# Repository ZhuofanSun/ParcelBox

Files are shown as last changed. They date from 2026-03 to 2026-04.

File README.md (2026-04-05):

# ParcelBox

ParcelBox is a Raspberry Pi smart parcel box prototype. It combines RFID access control, locker door actuation, live camera streaming, face detection with pan-tilt tracking, ultrasonic occupancy sensing, local audio/visual alerts, SQLite persistence, and a browser-based operations console into one device-side system.

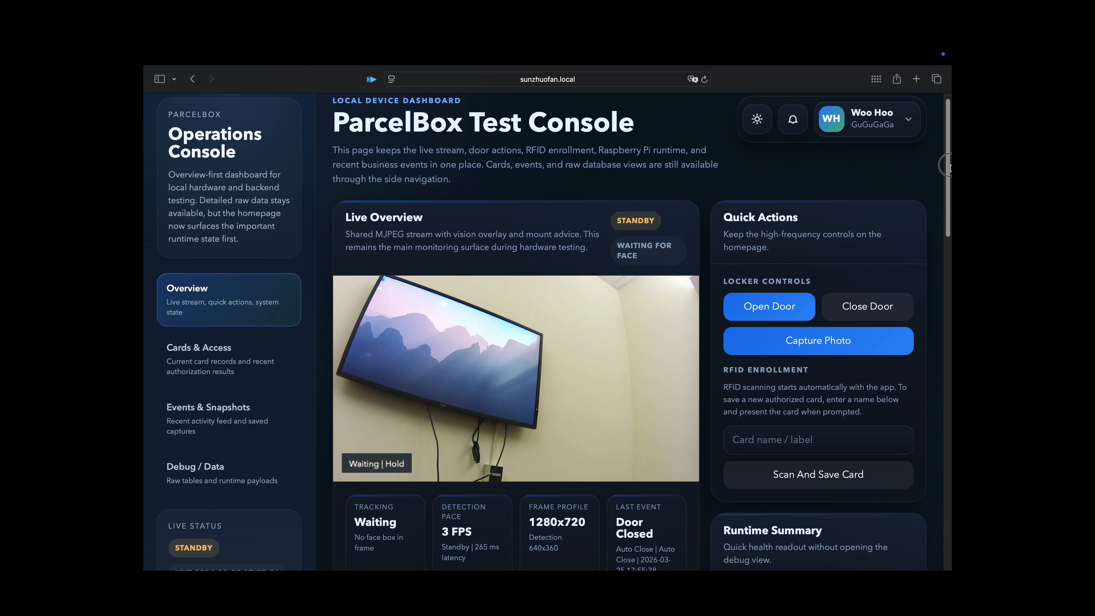
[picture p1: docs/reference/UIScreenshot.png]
ParcelBox dashboard


## Project Overview

The point of this project is not just to build a web page. It is to close the loop across a real hardware workflow:

- Read RFID cards and decide whether access should be granted
- Lock and unlock the compartment with a servo-driven door mechanism
- Provide live video, snapshots, and visual overlays from a CSI camera
- Detect faces, track them with a pan-tilt mount, recover from target loss, and drop into standby when idle
- Trigger door-open requests, email notifications, and local alarms from a physical button
- Persist cards, access attempts, door sessions, button requests, snapshots, and email schemes in local SQLite storage
- Expose the whole system through a browser console for monitoring, control, and debugging

This repository is scoped as a single-device prototype, not a cloud platform. The vision stack focuses on face detection and tracking rather than face recognition. Video delivery is handled with MJPEG plus WebSocket metadata instead of WebRTC.

## Team

- Zhuofan Sun - GitHub: [ZhuofanSun](https://github.com/ZhuofanSun)
- Jiayin Chen - GitHub: [Yinnc259](https://github.com/Yinnc259)
- Yangfei Wang - GitHub: [stayinnight1](https://github.com/stayinnight1)

## Showcase

### Events and Snapshots View

The homepage is meant for live status and quick control. The events and snapshots views are better for reviewing RFID activity, button requests, door sessions, and captured images.

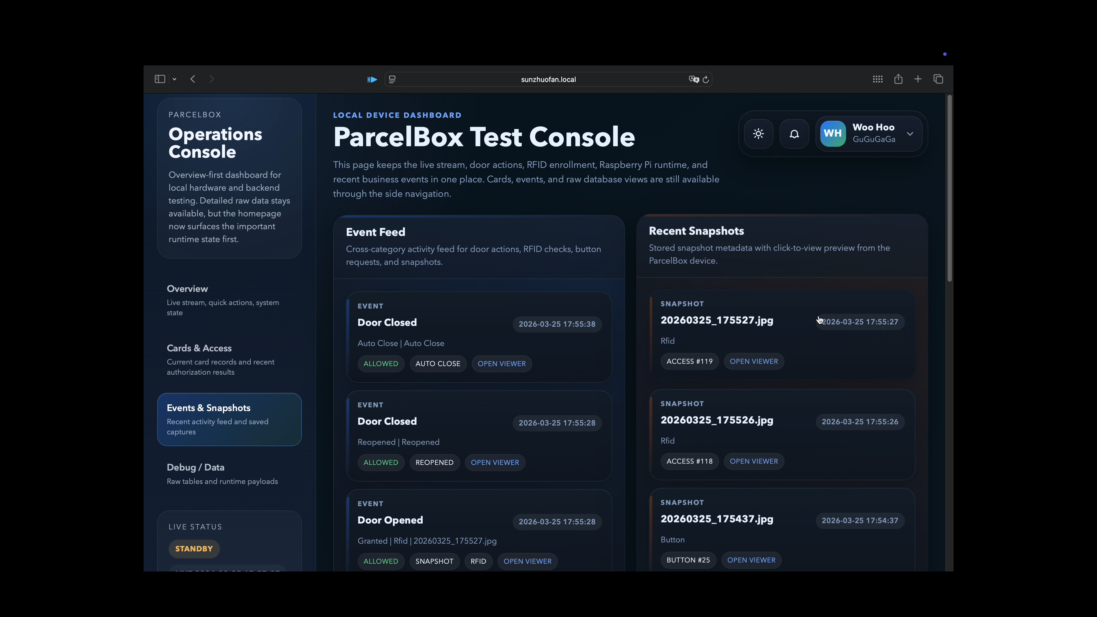
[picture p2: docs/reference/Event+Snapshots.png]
ParcelBox events and snapshots


### Hardware Wiring

The locker control hardware, camera mount, RFID reader, button, RGB LED, buzzer, and ultrasonic sensor are all wired around the Raspberry Pi. The following image is the most practical overall wiring reference for the prototype.

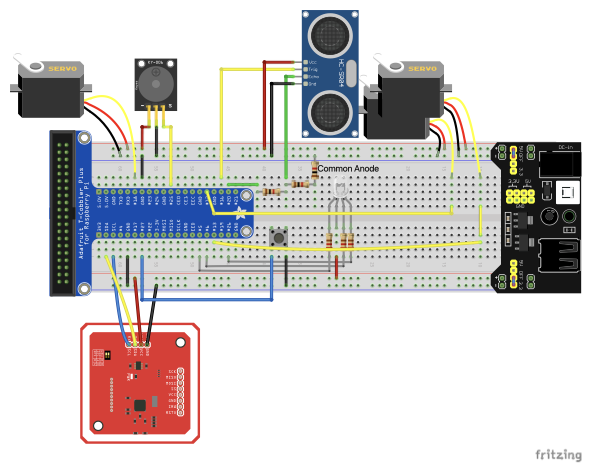
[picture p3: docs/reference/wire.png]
ParcelBox wiring diagram


If you want the schematic-style version, see [`docs/reference/wire_schem.png`](docs/reference/wire_schem.png).

## Core Capabilities

- Single-device integration: frontend, backend, drivers, and storage all run on the Raspberry Pi
- RFID access control: card enrollment, enable/disable state, and time-window authorization
- Locker workflow: open, close, auto-close, and post-close occupancy measurement
- Vision tracking: dual camera streams, low-resolution detection, high-resolution display, mount tracking, and standby mode
- Event capture: manual snapshots, RFID-triggered snapshots, button-triggered snapshots, and near-face snapshots
- Local alerts: unauthorized scans and repeated button presses can escalate to buzzer alarms and search behavior
- Browser operations console: live monitoring, event review, snapshot browsing, and device settings in one place

## Tech Stack

- Hardware: Raspberry Pi, PN532 RFID reader, CSI camera, 3 servo channels, ultrasonic sensor, button, RGB LED, buzzer
- Backend: FastAPI, Uvicorn, SQLite
- Vision: Picamera2, OpenCV, YuNet / Haar Cascade
- Frontend: plain HTML, CSS, and JavaScript
- Device control: `pigpio`, `RPi.GPIO`, Adafruit Blinka / PN532

## System Architecture

The repository is organized into five layers: browser console, web routes, core services, local data, and hardware drivers. `main.py` wires these services together at startup and exposes them through FastAPI.

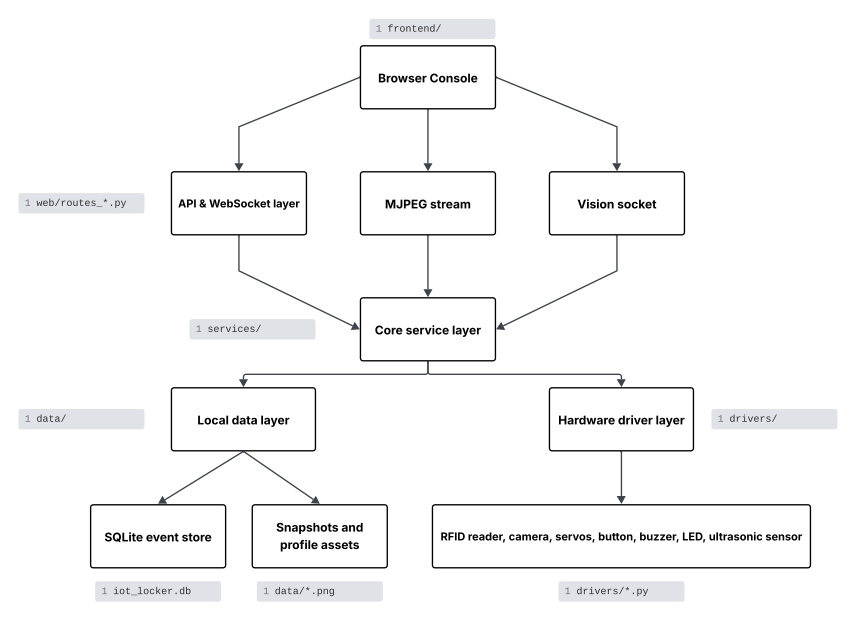
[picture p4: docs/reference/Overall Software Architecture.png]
Overall software architecture


The browser-to-device communication model is also intentionally simple:

- HTTP API for commands, settings writes, and polling-based status refresh
- MJPEG for the live video stream
- WebSocket for vision boxes, tracking state, button events, and other real-time overlay metadata

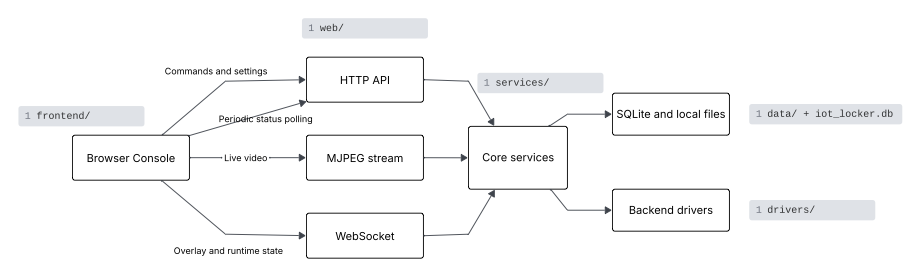
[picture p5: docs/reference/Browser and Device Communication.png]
Browser and device communication


## Main Workflows

### 1. RFID Unlock Flow

`LockerService` continuously polls `AccessService` in the background. When `AccessService` reads a UID from the PN532 reader, it normalizes the UID and evaluates whether the card exists, whether it is enabled, and whether the current time is inside the configured access window.

- If access is granted: record the result, capture a snapshot, drive the door servo open, and start the auto-close timer
- If access is denied: record the denied event, optionally attach a snapshot, and pass the event to `AlertService` for buzzer and escalation handling
- After the door closes: `OccupancyService` measures distance and classifies the locker as `occupied`, `empty`, or `door_not_closed`

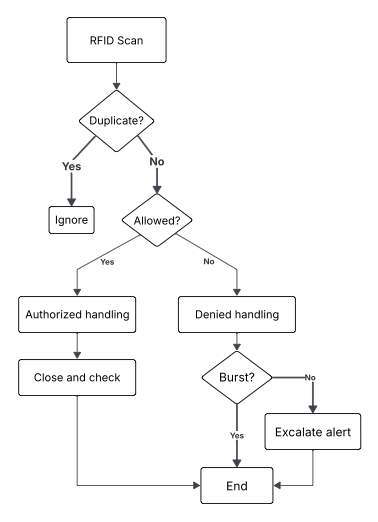
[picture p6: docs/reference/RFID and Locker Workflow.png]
RFID and locker workflow


### 2. Vision Detection and Pan-Tilt Tracking

`CameraService` maintains both the main stream and the lower-resolution detection stream. `VisionService` runs face detection on the detection stream, maps the boxes back to display resolution, and pushes the payload to the frontend over WebSocket. `CameraMountService` uses target offsets to drive the pan and tilt servos.

- Face detected: smooth the box, update the target center, and move the mount
- Face briefly lost: use short-term prediction to reduce visible jitter
- Face lost for longer: enter a recovery/search sweep, then return home if recovery fails
- No face for a while: drop to low-FPS standby mode to reduce idle load
- Face close enough to the camera: capture a one-time near-face snapshot

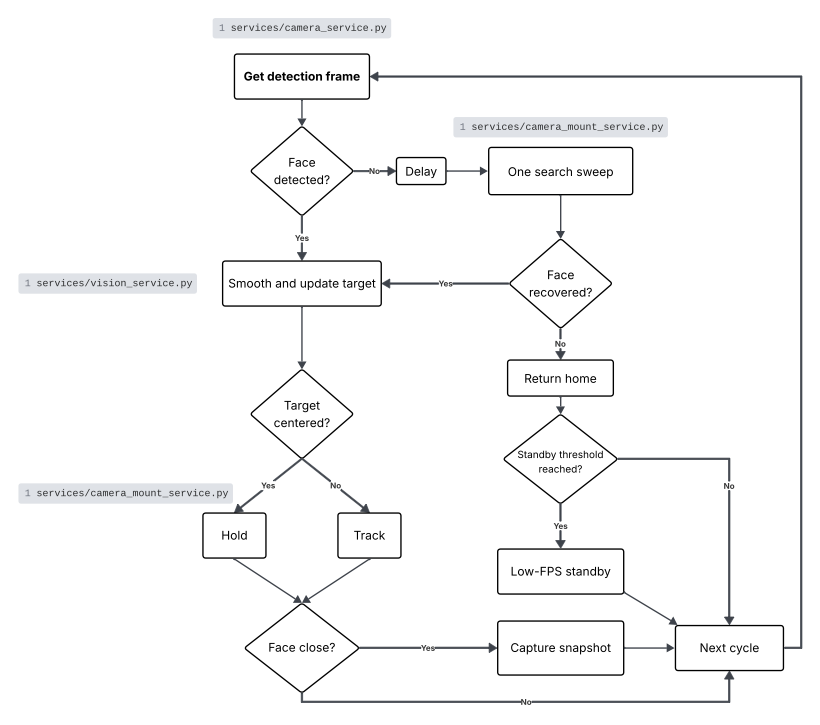
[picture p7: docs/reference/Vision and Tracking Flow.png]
Vision and tracking flow


### 3. Button, Notifications, and Event Flow

The system also maintains a separate hardware-button workflow:

- `ButtonService` listens to the GPIO button and can capture a snapshot and request an email notification
- `EmailNotificationService` sends a door-open request email using the currently enabled delivery scheme and applies duplicate suppression
- `AlertService` tracks burst conditions for rapid button presses and repeated unauthorized RFID scans
- `BuzzerService` and `LedService` provide local feedback
- `EventStore` consolidates button requests, snapshots, access attempts, and door sessions into SQLite for the frontend event and debug views

## Local Data Model

Runtime state is persisted in local SQLite storage. The main entities are:

- `rfid_card`: enrolled cards and their access rules
- `access_attempt`: the authorization result of each scan
- `door_session`: the full lifecycle of each open/close session
- `button_request`: button-triggered open requests and email delivery outcomes
- `snapshot`: captured images and their parent relationships
- `device_profile`: local console name, role, and avatar
- `email_subscription_scheme` / `email_subscription_recipient`: outbound email schemes and recipients

That means the card list, event feed, snapshot viewer, settings page, and debug tables in the browser are all reading from the same local source of truth.

## Project Structure

| Path | Role |
| --- | --- |
| `main.py` | Application entry point, service wiring, and FastAPI lifecycle setup |
| `config.py` | Central runtime configuration for GPIO, camera, mount, door, alerts, vision, web, and storage |
| `services/` | Business logic and background workers for RFID, locker control, vision, button handling, alerts, email, LEDs, and more |
| `web/` | FastAPI route layer for HTTP APIs, MJPEG streaming, and the vision WebSocket |
| `frontend/` | Static single-page console served directly by FastAPI, with no separate build step |
| `data/` | SQLite schema, `EventStore`, and snapshot path handling |
| `drivers/` | Low-level wrappers for the camera, PN532, servos, button, ultrasonic sensor, RGB LED, and buzzer |
| `scripts/` | Hardware smoke tests, Raspberry Pi sync scripts, runtime data pull scripts, and one-off migrations |
| `models/` | Vision model directory; the YuNet ONNX model is loaded from here by default |
| `docs/reference/` | UI screenshots, architecture diagrams, workflow diagrams, wiring references, and course materials |

If you want the fastest route through the codebase, this reading order works well:

1. `main.py`
2. `config.py`
3. `services/locker_service.py`
4. `services/access_service.py`
5. `services/camera_service.py`
6. `services/vision_service.py`
7. `services/camera_mount_service.py`
8. `data/event_store.py`
9. `web/routes_*.py`
10. `frontend/scripts/app.js`

## Key Modules

| Module | Responsibility |
| --- | --- |
| `AccessService` | RFID reads, card enrollment, and time-window authorization checks |
| `LockerService` | Scan processing, door state transitions, auto-close, and occupancy integration |
| `CameraService` | Camera initialization, shared stream frames, and snapshot capture |
| `VisionService` | Face detection, box smoothing, standby behavior, and near-face snapshot capture |
| `CameraMountService` | Home positioning, tracking, recovery, and search sweeps for the pan-tilt mount |
| `ButtonService` | Button listening, snapshot capture, and notification triggering |
| `AlertService` | Escalation logic for unauthorized scans and burst button activity |
| `EmailNotificationService` | Runtime email delivery for open requests and test emails |
| `EventStore` | SQLite persistence for cards, events, snapshots, settings, and email schemes |

## Runtime Boundaries

There are a few boundaries worth stating clearly:

- This is a single-device prototype, not a cloud multi-device platform
- Video uses MJPEG plus WebSocket because simplicity and stability matter more here than bandwidth efficiency
- Vision is limited to face detection and tracking, not identity recognition
- The frontend is plain static web content with no separate frontend build pipeline
- The best target environment is Raspberry Pi OS with working camera and GPIO access

## Before You Run It

Before starting the application, confirm the following:

- Raspberry Pi OS has camera and GPIO access enabled
- The hardware wiring matches the GPIO assignments in `config.py`
- `pigpiod` is available for stable servo control
- If you want YuNet, the model file exists at `models/face_detection_yunet_2023mar.onnx`
- If the YuNet model is missing, the OpenCV backend will fall back to Haar Cascade

## Installation and Startup

Install the Raspberry Pi system packages first:

```bash
sudo apt update
sudo apt install -y python3-picamera2 python3-opencv pigpio-tools python3-pigpio
```

Create a virtual environment and install the Python dependencies:

```bash
python3 -m venv .venv --system-site-packages
source .venv/bin/activate
pip install -r requirements.txt
```

`Picamera2` is installed as a system package, so the virtual environment keeps `--system-site-packages`.

Start `pigpiod`:

```bash
sudo systemctl enable --now pigpiod
```

If you want to run a quick hardware smoke test first:

```bash
./.venv/bin/python scripts/hardware_smoke_test.py all
```

Start the application:

```bash
./.venv/bin/python main.py
```

Then open the dashboard in a browser:

- `http://raspberrypi.local:8000`
- `http://<pi-lan-ip>:8000`

## Sync and Deploy to the Raspberry Pi

If you are developing on another machine and want to push the project to the Raspberry Pi, use the built-in sync script:

```bash
./scripts/sync_to_pi.sh
```

If you want to pull runtime data back from the Raspberry Pi, including the SQLite database and snapshots:

```bash
./scripts/pull_runtime_data_from_pi.sh
```

Both scripts support environment-variable overrides for the target host and path:

```bash
PI_HOST=<your-pi-host> PI_USER=<your-pi-user> PI_PORT=22 REMOTE_DIR=<remote-path> ./scripts/sync_to_pi.sh
```

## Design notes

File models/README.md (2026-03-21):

# Vision Models

The current Phase 2 baseline uses the `opencv` vision backend, so this folder is not
required for the first working person / face detection loop.

This folder currently holds the active OpenCV vision models used by the project.

Current reserved paths from [config.py](/Users/sunzhuofan/IOT-project/config.py):

- `models/object_detection_nanodet_2022nov.onnx`
- `models/face_detection_yunet_2023mar.onnx`

Current recommended person model path:

- `models/object_detection_nanodet_2022nov.onnx`

Optional lighter fallback:

- `models/object_detection_nanodet_2022nov_int8bq.onnx`

Current recommended face model path:

- `models/face_detection_yunet_2023mar.onnx`

If the YuNet model is not present, the OpenCV vision backend falls back to Haar cascade.

reference link:

https://huggingface.co/opencv

https://huggingface.co/opencv/face_detection_yunet/tree/main

https://huggingface.co/opencv/opencv_zoo

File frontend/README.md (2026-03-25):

# Frontend Notes

当前前端仍然是“单设备调试操作台”，不引入新的构建链，也不把 `Tabler` 整体搬进来。这里的目标是保留原生 `HTML + CSS + JS` 的低门槛，同时把结构拆清楚，后续加 `dark mode`、通知铃铛、profile、设备级设置页时不再回到一个超长单文件里摸索。

## Directory Map

- `index.html`
  - 只保留页面结构、视图容器和少量页面级内联布局。
  - 当前入口仍然是单页，侧栏切换 `Overview / Cards / Events / Debug`，profile 菜单还可以打开独立的 `Settings` 视图。
- `styles/theme.css`
  - 主题变量、背景、全局字体和基础色板。
  - 未来做 `dark mode` 时，优先在这里加 `data-theme="dark"` 对应变量。
- `styles/layout.css`
  - 页面骨架：侧栏、工作区、主栅格、响应式断点。
  - 如果后面增加 topbar、profile 页面容器、settings 页面壳子，优先放这里。
- `styles/components.css`
  - 面板、卡片、按钮、表格、toast、视频叠加区等组件样式。
  - 视觉微调大多会落在这里。
- `scripts/dom.js`
  - 所有当前页面依赖的 DOM 引用和 canvas context。
- `scripts/state.js`
  - 前端运行时状态和轮询 / WebSocket 常量。
- `scripts/formatters.js`
  - 时间、标签、状态文本、人类可读化等纯函数。
- `scripts/renderers.js`
  - 负责把状态渲染到页面上，也包括视频框 overlay 绘制。
- `scripts/api.js`
  - `fetchJson`、各个后端接口调用、页面刷新动作。
- `scripts/app.js`
  - 应用入口、事件绑定、WebSocket、轮询、页面 bootstrap。

## Current Rules

- 保持“无前端框架、无构建链”前提，文件直接被 FastAPI 静态托管。
- 优先把新功能加进现有模块，不要把逻辑重新塞回 `index.html`。
- 如果只是改展示文案或区块结构，优先动 `index.html`。
- 如果是主题、阴影、卡片视觉、topbar 样式，优先动 `styles/`。
- 如果是接口调用、轮询、WebSocket、通知逻辑，优先动 `scripts/`。

## Header Tools

- 右上角全局工具区已经接入：
  - `dark mode` 开关，主题选择写入 `localStorage`
  - 通知铃铛，当前只展示高价值提醒：按钮按下、未授权刷卡、近距离人脸触发
  - profile trigger，下拉菜单承接后续设备设置入口

## Settings View

- 已接入一个本地 settings 视图，通过 profile dropdown 进入。
- 当前可配置：
  - 控制台显示名称
  - 角色 / 副标题文案
  - 主题偏好
  - 头像上传 / 重置
  - `Display Name -> initials` 默认头像
  - 通知铃铛里三类提醒的开关
  - 设备级邮件方案：
    - 方案选择 / 覆盖保存 / 另存为新方案 / 删除
    - `username` / `password` / `from_address`
    - 多个订阅邮箱
    - 测试邮件
- 主题和铃铛筛选仍写浏览器本地存储。
- profile 名称、角色、头像，以及邮件方案现在都走后端设备级持久化。

## Planned UI Extensions

- profile / settings：
  - 设备级 profile 页面和更完整的本机设置
  - `Events & Snapshots` 的图片预览与查看

## Tabler Usage Boundary

- `Tabler` 目前只作为骨架、组件层次和交互动效参考。
- 不直接复制整套模板文件结构。
- 需要参考时，优先借鉴：
  - topbar 工具区
  - avatar / profile dropdown
  - theme toggle
  - card 层次和列表信息密度

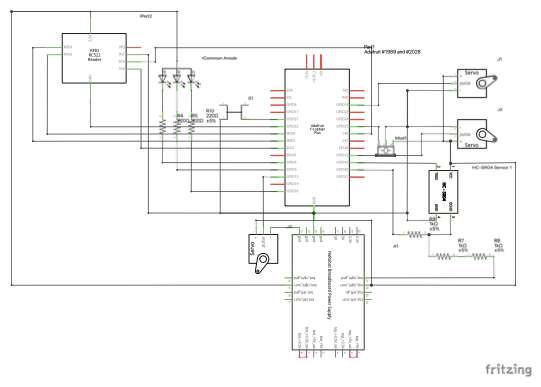
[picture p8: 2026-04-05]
docs/reference/wire_schem.png

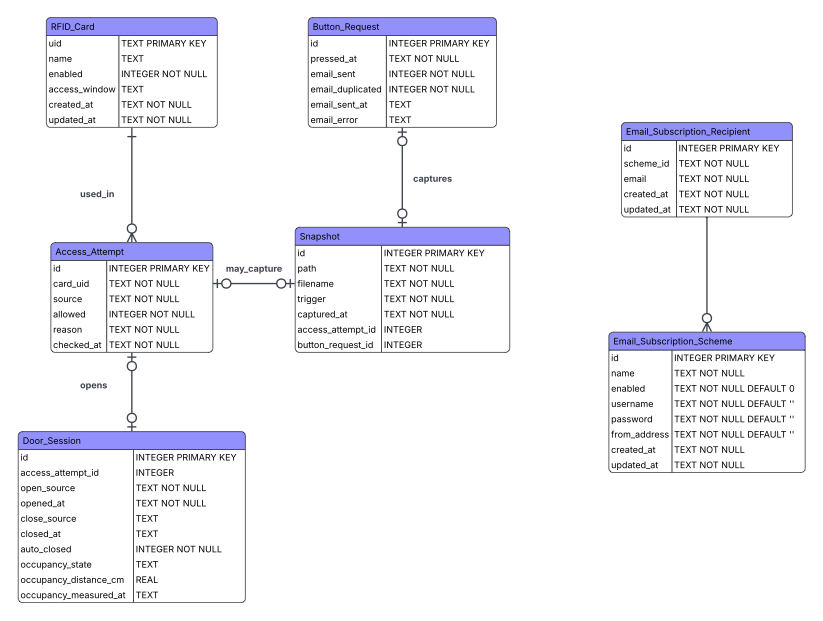
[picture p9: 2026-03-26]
docs/reference/ERD_Full.png

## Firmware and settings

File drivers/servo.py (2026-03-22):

"""Standard servo driver with hardware-timed pigpio support.

Notes:
- `pigpio` is preferred because it uses hardware-timed pulses and is much more
  stable than `RPi.GPIO.PWM` under CPU load.
- The driver falls back to `RPi.GPIO` software PWM when pigpio is unavailable.
- Calibrate angle range and pulse range on the real servo before using the end points.
- Use an external 5V supply for the servo and keep grounds shared with the Pi.
"""

from __future__ import annotations

import time

try:
    import pigpio
except ImportError:  # pragma: no cover - optional dependency on Raspberry Pi
    pigpio = None

try:
    import RPi.GPIO as GPIO
except ImportError:  # pragma: no cover - optional dependency on Raspberry Pi
    GPIO = None


class _PigpioServoBackend:
    """Drive a servo through pigpio's hardware-timed servo pulses."""

    backend_name = "pigpio"

    def __init__(self, pin: int, *, pigpio_module=None) -> None:
        module = pigpio_module or pigpio
        if module is None:
            raise RuntimeError("pigpio is not available")

        client = module.pi()
        if client is None or not getattr(client, "connected", False):
            if client is not None and hasattr(client, "stop"):
                client.stop()
            raise RuntimeError("pigpio daemon is unavailable")

        self.pin = pin
        self._module = module
        self._client = client
        self._client.set_mode(self.pin, self._module.OUTPUT)

    def write_pulse_width_ms(self, pulse_width_ms: float) -> None:
        self._client.set_servo_pulsewidth(self.pin, int(round(pulse_width_ms * 1000)))

    def release(self) -> None:
        self._client.set_servo_pulsewidth(self.pin, 0)

    def cleanup(self) -> None:
        try:
            self.release()
        finally:
            self._client.stop()


class _RpiGpioServoBackend:
    """Drive a servo through RPi.GPIO software PWM."""

    backend_name = "rpi_gpio"

    def __init__(self, pin: int, *, frequency: int, gpio_module=None) -> None:
        module = gpio_module or GPIO
        if module is None:
            raise RuntimeError("RPi.GPIO is not available")

        self.pin = pin
        self._gpio = module
        self._frequency = frequency

        if self._gpio.getmode() is None:
            self._gpio.setmode(self._gpio.BCM)

        self._gpio.setup(self.pin, self._gpio.OUT)
        self._pwm = self._gpio.PWM(self.pin, self._frequency)
        self._pwm.start(0)

    def write_pulse_width_ms(self, pulse_width_ms: float) -> None:
        period_ms = 1000 / self._frequency
        duty_cycle = pulse_width_ms / period_ms * 100
        self._pwm.ChangeDutyCycle(duty_cycle)

    def release(self) -> None:
        self._pwm.ChangeDutyCycle(0)

    def cleanup(self) -> None:
        self.release()
        self._pwm.stop()
        self._gpio.cleanup(self.pin)


class Servo:
    """Simple driver for a standard servo motor."""

    def __init__(
        self,
        pin: int,
        min_angle: float = 0,
        max_angle: float = 180,
        min_pulse_width: float = 0.5,
        max_pulse_width: float = 2.5,
        frequency: int = 50,
        backend: str = "auto",
        gpio_module=None,
        pigpio_module=None,
    ) -> None:
        """
        Initialize the servo.

        Args:
            pin: BCM GPIO pin connected to the servo signal wire.
            min_angle: Minimum angle supported by this servo.
            max_angle: Maximum angle supported by this servo.
            min_pulse_width: Pulse width in milliseconds for min_angle.
            max_pulse_width: Pulse width in milliseconds for max_angle.
            frequency: PWM frequency in Hz. Standard servos usually use 50 Hz.
            backend: "auto", "pigpio", or "rpi_gpio".
            gpio_module: Optional GPIO-compatible module for testing or mocking.
            pigpio_module: Optional pigpio-compatible module for testing or mocking.
        """
        if min_angle >= max_angle:
            raise ValueError("min_angle must be smaller than max_angle")
        if min_pulse_width <= 0 or max_pulse_width <= 0:
            raise ValueError("pulse widths must be > 0")
        if min_pulse_width >= max_pulse_width:
            raise ValueError("min_pulse_width must be smaller than max_pulse_width")
        if frequency <= 0:
            raise ValueError("frequency must be > 0")

        normalized_backend = str(backend).strip().lower()
        if normalized_backend not in {"auto", "pigpio", "rpi_gpio"}:
            raise ValueError("backend must be one of: auto, pigpio, rpi_gpio")

        self.pin = pin
        self.min_angle = min_angle
        self.max_angle = max_angle
        self.min_pulse_width = min_pulse_width
        self.max_pulse_width = max_pulse_width
        self.frequency = frequency
        self._current_angle = None
        self._backend = self._build_backend(
            normalized_backend,
            gpio_module=gpio_module,
            pigpio_module=pigpio_module,
        )

    @property
    def current_angle(self):
        """Return the last angle sent to the servo."""
        return self._current_angle

    @property
    def backend_name(self) -> str:
        """Return the active PWM backend name."""
        return self._backend.backend_name

    def _build_backend(self, backend: str, *, gpio_module=None, pigpio_module=None):
        if backend == "pigpio":
            return _PigpioServoBackend(self.pin, pigpio_module=pigpio_module)

        if backend == "rpi_gpio":
            return _RpiGpioServoBackend(self.pin, frequency=self.frequency, gpio_module=gpio_module)

        pigpio_error = None
        try:
            return _PigpioServoBackend(self.pin, pigpio_module=pigpio_module)
        except Exception as error:
            pigpio_error = error

        try:
            return _RpiGpioServoBackend(self.pin, frequency=self.frequency, gpio_module=gpio_module)
        except Exception as error:
            raise RuntimeError(
                "No usable servo backend is available. "
                f"pigpio failed with: {pigpio_error}; "
                f"RPi.GPIO failed with: {error}"
            ) from error

    def _validate_angle(self, angle: float) -> None:
        if not self.min_angle <= angle <= self.max_angle:
            raise ValueError(
                f"angle must be between {self.min_angle} and {self.max_angle}"
            )

    def _angle_to_pulse_width(self, angle: float) -> float:
        angle_range = self.max_angle - self.min_angle
        pulse_range = self.max_pulse_width - self.min_pulse_width
        return self.min_pulse_width + ((angle - self.min_angle) / angle_range) * pulse_range

    def release(self) -> None:
        """Stop sending PWM to reduce jitter after moving."""
        self._backend.release()

    def set_angle(self, angle: float, settle_time: float = 0.3, release: bool = True) -> None:
        """
        Move the servo to a target angle.

        Args:
            angle: Target angle to move to.
            settle_time: Time in seconds to wait for the servo to reach the target.
            release: If True, stop PWM after the move to reduce jitter.
        """
        if settle_time < 0:
            raise ValueError("settle_time must be >= 0")

        self._validate_angle(angle)
        pulse_width = self._angle_to_pulse_width(angle)
        self._backend.write_pulse_width_ms(pulse_width)
        self._current_angle = angle

        if settle_time > 0:
            time.sleep(settle_time)

        if release:
            self.release()

    def center(self, settle_time: float = 0.3, release: bool = True) -> None:
        """
        Move the servo to the center angle.

        Args:
            settle_time: Time in seconds to wait for the servo to reach the target.
            release: If True, stop PWM after the move to reduce jitter.
        """
        center_angle = (self.min_angle + self.max_angle) / 2
        self.set_angle(center_angle, settle_time, release)

    def move_min(self, settle_time: float = 0.3, release: bool = True) -> None:
        """
        Move the servo to the minimum angle.

        Args:
            settle_time: Time in seconds to wait for the servo to reach the target.
            release: If True, stop PWM after the move to reduce jitter.
        """
        self.set_angle(self.min_angle, settle_time, release)

    def move_max(self, settle_time: float = 0.3, release: bool = True) -> None:
        """
        Move the servo to the maximum angle.

        Args:
            settle_time: Time in seconds to wait for the servo to reach the target.
            release: If True, stop PWM after the move to reduce jitter.
        """
        self.set_angle(self.max_angle, settle_time, release)

    def move_to(
        self,
        angle: float,
        step: float = 1,
        delay: float = 0.02,
        release: bool = True,
    ) -> None:
        """
        Move the servo gradually to a target angle.

        Args:
            angle: Final target angle.
            step: Angle step used for each small move.
            delay: Delay in seconds between steps.
            release: If True, stop PWM after the move to reduce jitter.
        """
        if step <= 0:
            raise ValueError("step must be > 0")
        if delay < 0:
            raise ValueError("delay must be >= 0")

        self._validate_angle(angle)

        if self._current_angle is None:
            self.set_angle(angle, 0.3, release)
            return

        current = self._current_angle

        if angle > current:
            while current < angle:
                current = min(current + step, angle)
                self.set_angle(current, 0, False)
                time.sleep(delay)
        else:
            while current > angle:
                current = max(current - step, angle)
                self.set_angle(current, 0, False)
                time.sleep(delay)

        self._current_angle = angle

        if release:
            self.release()

    def move_by(self, delta: float, settle_time: float = 0.2, release: bool = True) -> float:
        """
        Move the servo by a relative angle delta.

        Args:
            delta: Relative angle to add to the current angle.
            settle_time: Time in seconds to wait after the move.
            release: If True, stop PWM after the move to reduce jitter.
        """
        if self._current_angle is None:
            current = (self.min_angle + self.max_angle) / 2
        else:
            current = self._current_angle

        target = current + delta
        self.set_angle(target, settle_time, release)
        return target

    def sweep(
        self,
        start_angle: float,
        end_angle: float,
        step: float = 2,
        delay: float = 0.02,
        release: bool = True,
    ) -> None:
        """
        Sweep the servo from one angle to another.

        Args:
            start_angle: Sweep start angle.
            end_angle: Sweep end angle.
            step: Angle step used for each small move.
            delay: Delay in seconds between steps.
            release: If True, stop PWM after the sweep to reduce jitter.
        """
        self.set_angle(start_angle, 0.2, False)
        self.move_to(end_angle, step, delay, release)

    def cleanup(self) -> None:
        """Stop PWM and release the GPIO resources."""
        self._backend.cleanup()

    def close(self) -> None:
        """Alias of cleanup()."""
        self.cleanup()


if __name__ == "__main__":
    TEST_PIN = 13

    servo = Servo(TEST_PIN)
    try:
        print(f"Servo backend: {servo.backend_name}")
        servo.move_min()
        time.sleep(1)
        servo.center()
        time.sleep(1)
        servo.move_max(settle_time=1.0, release=False)
        time.sleep(1)
        servo.move_to(45, 2, 0.02)
        time.sleep(1)
        servo.move_to(180, 2, 0.02)
        time.sleep(1)
        servo.sweep(45, 120, 2, 0.02)
        servo.center()
        servo.move_to(120, 1, 0.02)
    finally:
        servo.cleanup()

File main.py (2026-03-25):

"""Phase 3 app entrypoint."""

from __future__ import annotations

import logging
from contextlib import asynccontextmanager
from pathlib import Path

import uvicorn
from fastapi import FastAPI
from fastapi.staticfiles import StaticFiles

from config import config
from services.access_service import AccessService
from services.alert_service import AlertService
from services.button_service import ButtonService
from services.buzzer_service import BuzzerService
from services.camera_service import CameraService
from services.camera_mount_service import CameraMountService
from services.email_service import EmailNotificationService
from services.email_settings_service import EmailSettingsService
from services.led_service import LedService
from services.locker_service import LockerService
from services.occupancy_service import OccupancyService
from services.profile_settings_service import ProfileSettingsService
from services.system_status_service import SystemStatusService
from services.vision_service import VisionService
from data.event_store import EventStore
from web.routes_cards import build_cards_router
from web.routes_control import build_control_router
from web.routes_logs import build_logs_router
from web.routes_settings import build_settings_router
from web.routes_snapshots import build_snapshot_router
from web.routes_stream import begin_stream_shutdown, build_stream_router, reset_stream_shutdown_state
from web.routes_system import build_system_router

logger = logging.getLogger(__name__)


camera_service = CameraService()
event_store = EventStore()
camera_service.set_snapshot_prune_callback(event_store.delete_snapshots_by_paths)
vision_service = VisionService(camera_service, event_store=event_store)
camera_mount_service = CameraMountService(vision_service)
vision_service.set_standby_anchor_provider(camera_mount_service.get_standby_anchor_timestamp)
camera_service.set_stream_standby_provider(vision_service.is_standby_active)
system_status_service = SystemStatusService()
profile_settings_service = ProfileSettingsService(event_store)
email_settings_service = EmailSettingsService(event_store)
email_service = EmailNotificationService(email_settings_service)
buzzer_service = BuzzerService()
alert_service = AlertService(buzzer_service, camera_mount_service)
button_service = ButtonService(
    snapshot_callback=camera_service.capture_snapshot,
    notification_callback=email_service.send_open_request_email,
    alert_callback=alert_service.handle_button_pressed,
    event_store=event_store,
)
access_service = AccessService(
    event_store=event_store,
    card_detect_callback=buzzer_service.beep_card_detected,
)
occupancy_service = OccupancyService()
locker_service = LockerService(
    access_service,
    occupancy_service,
    snapshot_callback=camera_service.capture_snapshot,
    alert_callback=alert_service.handle_access_denied,
    event_store=event_store,
)
camera_mount_service.set_alert_search_complete_callback(alert_service.on_alert_search_completed)
led_service = LedService(
    vision_service=vision_service,
    camera_mount_service=camera_mount_service,
    locker_service=locker_service,
    button_service=button_service,
)


def configure_logging() -> None:
    """Configure application logging for local runs."""
    if logging.getLogger().handlers:
        return
    logging.basicConfig(
        level=logging.INFO,
        format="%(asctime)s %(levelname)s %(name)s: %(message)s",
    )


@asynccontextmanager
async def lifespan(app: FastAPI):
    reset_stream_shutdown_state()
    logger.info("Application startup sequence begin")
    buzzer_service.start()
    logger.info("Buzzer service started")
    access_service.start()
    logger.info("Access service started")
    occupancy_service.start()
    logger.info("Occupancy service started")
    event_store.start()
    logger.info("Event store started")
    camera_service.start()
    logger.info("Camera service started")
    button_service.start()
    logger.info("Button service started")
    vision_service.start()
    logger.info("Vision service started")
    locker_service.start()
    logger.info("Locker service started")
    camera_mount_service.start()
    logger.info("Camera mount service started")
    led_service.start()
    logger.info("LED service started")
    try:
        yield
    finally:
        logger.info("Application shutdown sequence begin")
        await begin_stream_shutdown()
        led_service.stop()
        camera_mount_service.stop()
        locker_service.stop()
        vision_service.stop()
        button_service.stop()
        camera_service.stop()
        event_store.stop()
        occupancy_service.stop()
        access_service.stop()
        buzzer_service.stop()
        logger.info("Application shutdown sequence complete")


app = FastAPI(title="ParcelBox", lifespan=lifespan)
app.include_router(
    build_stream_router(
        camera_service,
        vision_service,
        camera_mount_service,
        button_service,
        event_store,
    )
)
app.include_router(build_control_router(locker_service, alert_service))
app.include_router(build_cards_router(access_service, locker_service))
app.include_router(build_logs_router(event_store, alert_service))
app.include_router(build_snapshot_router(event_store))
app.include_router(build_system_router(system_status_service))
app.include_router(build_settings_router(profile_settings_service, email_settings_service, email_service))

frontend_dir = Path(__file__).resolve().parent / "frontend"
app.mount("/", StaticFiles(directory=frontend_dir, html=True), name="frontend")


def serve() -> None:
    """Run the local web server."""
    configure_logging()
    logger.info(
        "Starting ParcelBox web server on %s:%s",
        config.web.host,
        config.web.port,
    )
    uvicorn.run(
        app,
        host=config.web.host,
        port=config.web.port,
        reload=False,
        access_log=config.web.access_log,
        timeout_graceful_shutdown=1,
    )


if __name__ == "__main__":
    serve()

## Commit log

2026-03-18 add buzzer drive
    [wire.fzz]
2026-03-18 Add button drive
    [wire.fzz]
2026-03-18 add camera drive; rgb drive; servo drive;
2026-03-18 rpi mod
    [wire.fzz]
2026-03-18 add motion sensor drive
2026-03-18 rpi mod motion sensor
2026-03-19 modify pin
2026-03-19 add test, change servo angle
2026-03-19 Add camera_service; vision_service(demo);add basic web
2026-03-19 increase fps; fix RGB8888 channel
    [camera_service.py, config.py]
2026-03-20 All front-end clients share the same up-to-date cached frame; Fixed the stop/start lifecycle; Fixed low-resolution color conversion
    [camera.py, camera_service.py, vision_service.py]
2026-03-20 Camera config add hflip&vflip
2026-03-20 switch http to websocket; CV part in new thread
2026-03-21 opt backend interrupt speed; moving forward
2026-03-22 switch to hardware pwm
2026-03-22 add video standby mode; opt search; opt track
2026-03-23 add led logic; read+buzzer
    [access_service.py, buzzer_service.py, camera_mount_service.py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]
2026-03-23 fix led green flash bug; add tests; remove frontend metadata; add backend log
    [access_service.py, button_service.py, camera_mount_service.py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]
2026-03-23 fix no face standby;
    [config.py, led_service.py, vision_service.py]
2026-03-23 fix rfid polling bug
    [access_service.py, config.py]
2026-03-24 Fixed a read bug that occurred when importing data from the old system. Removed manual polling for card reads. Restored the ability to save new cards.
    [access_service.py, locker_service.py]
2026-03-25 修复了一些错误并增加了一些功能 > v <
    [config.py, email_service.py, email_settings_service.py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]
